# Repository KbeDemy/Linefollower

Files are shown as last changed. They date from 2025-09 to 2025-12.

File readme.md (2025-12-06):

# LineFollower

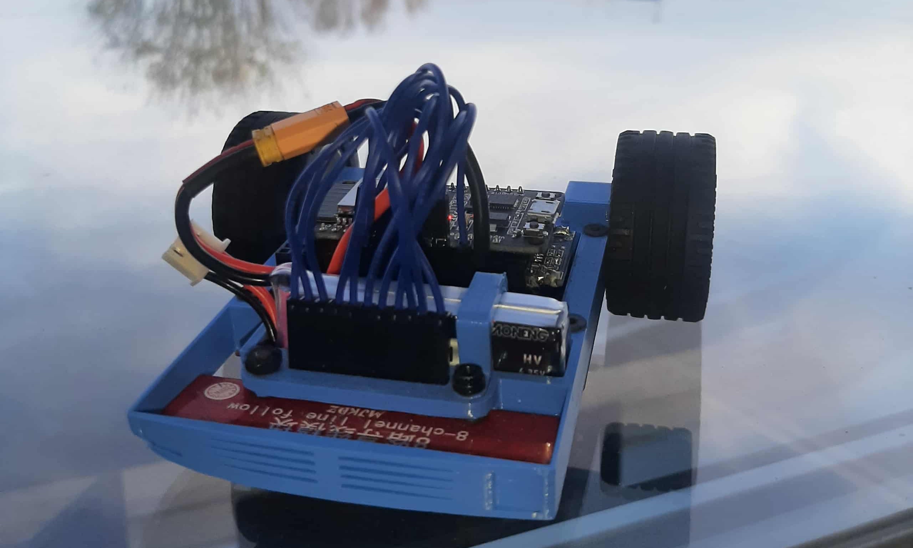
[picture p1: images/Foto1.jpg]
A description of my image


## specifications

microcontroller: ESP32-S3

motors: Aslong JGA12-N20-30 DC-Transmissiemotor 6V - 500RPM 

h-bridge: TB6612FNG 

sensors: 8x IR Lijn Tracking Module

batteries: LIHV 2s 300mAh

wireless communication: Bleutooth

distance sensor - motors: 90mm

weight: 150 Gr

speed: 0.27 m/s

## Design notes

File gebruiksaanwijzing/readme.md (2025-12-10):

Gebruikershandleiding: LineFollow Robot

Deze handleiding beschrijft de veilige werking, draadloze bediening en configuratie van de LineFollow robot via de bijbehorende applicatie.
Veiligheidsinstructies: Batterijgebruik
Opladen & Batterijtype

De robot gebruikt een LiPo HV 2S batterij met een volledige spanning van 8.7 V. Dit type batterij vereist uiterste voorzichtigheid.

    GEVAAR! LiPo-batterijen zijn zeer brandgevaarlijk bij onjuist gebruik of beschadiging.

    Gebruik enkel de juiste, door de fabrikant gespecificeerde LiPo-lader.

    Laad de batterij altijd op met de individuele cel-balansdraad aangesloten om overladen en celonbalans te voorkomen.

    Zorg dat de batterij fysiek is losgekoppeld van de robot tijdens het opladen.

    De robot en de USB poort van uw computer kan niet tegelijk de USB en de batterij aan doe dit nooit!
Robot Aan/Uit Schakelen

De robot is niet voorzien van een fysieke aan/uit-schakelaar.

    AAN: Sluit de batterij aan op de robot.

    UIT: Koppel de batterij fysiek los van de robot.

Draadloze Communicatie & GUI Bediening

De robot communiceert via Bluetooth met de GUI, waardoor er geen handmatige commando's nodig zijn.
Verbinding Maken / Verbreken
Actie	Procedure
Verbinden	
1. Zorg dat de robot is ingeschakeld (batterij aangesloten).
2. Open de app en ga naar de Connectie Tab.
3. Druk op de knop Verbinden. De app zal de status 'Verbonden' weergeven.
   
Verbreken	
De verbinding wordt verbroken door: 
1. In de app op Verbreken te drukken.
2. De applicatie te sluiten.
3. De batterij fysiek uit de robot te halen.

De Vier Applicatie Tabs
1. Connectie Tab 

Toont de huidige verbindingsstatus en bevat de knoppen Verbinden en Verbreken.
2. Sensoren Tab 

Deze tab geeft de live data van de lijnsensoren weer.

    Visualisatie: Een balkgrafiek toont de uitgelezen sensorwaarden.

    Besturingsknoppen:
        Kalibreer Wit/Zwart: Zie de sectie Kalibratie hieronder.

3. Settings Tab
   
Deze tab is bedoeld voor het configureren van de robotparameters.
      
      Start: Start de automatische lijnvolgroutine (PID-controle).
      Stop: Stopt de robot onmiddellijk en schakelt de PID-lus uit.
      Parameters: 
      de Basis Snelheid (0-255), 
      
      de PID-parameters (Kp, Ki, Kd) 
      
      het minimaal contrast tussen zwart en wit wanneer de robot uitvalt en
      
      de loogdaarlaatfilter op de position.
      
      Testmodus (ZQSD): Dit biedt de mogelijkheid om de motoren manueel te testen en besturen met de ZQSD-toetsen (of vergelijkbare controls).

      Belangrijk: Manuele besturing is alleen mogelijk wanneer u in deze tab bent. Dit is handig om de robot na lijnverlies snel en handmatig terug op de lijn te plaatsen.

5. Plot Tab 

Deze tab dient voor het analyseren van de prestaties na een run.

    Run Selectie: U kunt eerder uitgevoerde runs selecteren en de data ervan terugkijken.

    Plot Opties: U kunt kiezen welke data wordt weergegeven:

        Individuele sensorwaarden.

        Configuratie-instellingen van de run (Kp, Ki, Kd, Speed).

        De cruciale regelvariabelen: Output (de stuurcorrectie van de PID-regelaar) en Position (de berekende lijnpositie).

Analyse: U kunt inzoomen op de grafiek om oscillatie te detecteren en uw PID-instellingen te finetunen.
Shutterstock

    Verkennen

Kalibratie (Normalisatie)

Kalibratie is het proces waarbij de sensorwaarden softwarematig worden genormaliseerd. Dit zorgt ervoor dat de robot de maximale contrastinformatie tussen de witte ondergrond en de zwarte lijn benut, en maakt de sensoren onderling gelijk.
Stappenplan

    Installeer de App: Ga naar de Connectie Tab en verbind met de robot.

    Kalibratie WIT (Minimale Waarden):

        Plaatsing: Plaats de robot op de witte achtergrond van het parcours dat u gaat gebruiken.

        Controle: Ga naar de Sensoren Tab en controleer of alle sensorbalken een lage waarde (bijna allemaal 'wit') aangeven.

        Uitvoeren: Druk op de knop Kalibreer WIT.

    Kalibratie ZWART (Maximale Waarden):

        Plaatsing: Plaats de robot met de sensoren direct op de zwarte lijn van het parcours.

        Controle: Ga naar de Sensoren Tab en controleer of alle sensorbalken een hoge waarde (bijna allemaal 'zwart') aangeven.

        Uitvoeren: Druk op de knop Kalibreer ZWART.

Let op: Het is cruciaal dat u deze stappen uitvoert op de exacte materialen (wit/zwart) die u tijdens de run zult gebruiken.

Aanbevolen Parameters

De robot rijdt stabiel met de volgende parameters:

Kp	7	

Ki	0	

Kd	0	

Speed	140 	De basissnelheid van de robot.

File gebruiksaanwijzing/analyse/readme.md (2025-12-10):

#  Analyse van het Linefollower Project

Dit document vat de bevindingen en conclusies samen die zijn voortgekomen uit de analysefase van de linefollower-robot. Het project toonde aan dat de beperkingen van de mechanische constructie de prestaties van zelfs geavanceerde softwarematige oplossingen (zoals PID) overtroeven.

---

## 1.  De Logica van de PID-Regelaar

### Uitgebreide Testen vs. Mechanische Beperkingen
Tijdens de ontwikkelingsfase is er uitgebreid geëxperimenteerd met verschillende soorten en configuraties van de PID-regelaar. Hoewel de PID-logica essentieel is voor het sturen, werd al snel duidelijk dat verdere optimalisatie van de parameters of de implementatie **geen significante snelheidsverbetering** meer opleverde.

De primaire reden hiervoor is de **constructie van de robot**. De batterij, die een aanzienlijk gewicht vormt, is te ver van de motorassen geplaatst. Dit verhoogt het traagheidsmoment en de onbalans, waardoor de robot fysiek niet in staat is om sneller door bochten te gaan, onafhankelijk van hoe perfect de PID-correctie ook is. De gewichtsverdeling zou idealiter **dichter bij de motorassen** moeten liggen.

---

## 2.  Sensor Data en de Vreemde 'Glitch'

### Het Filter dat de Robot Vertraagde

Toen ik grafiek bekeek (de afbeelding):
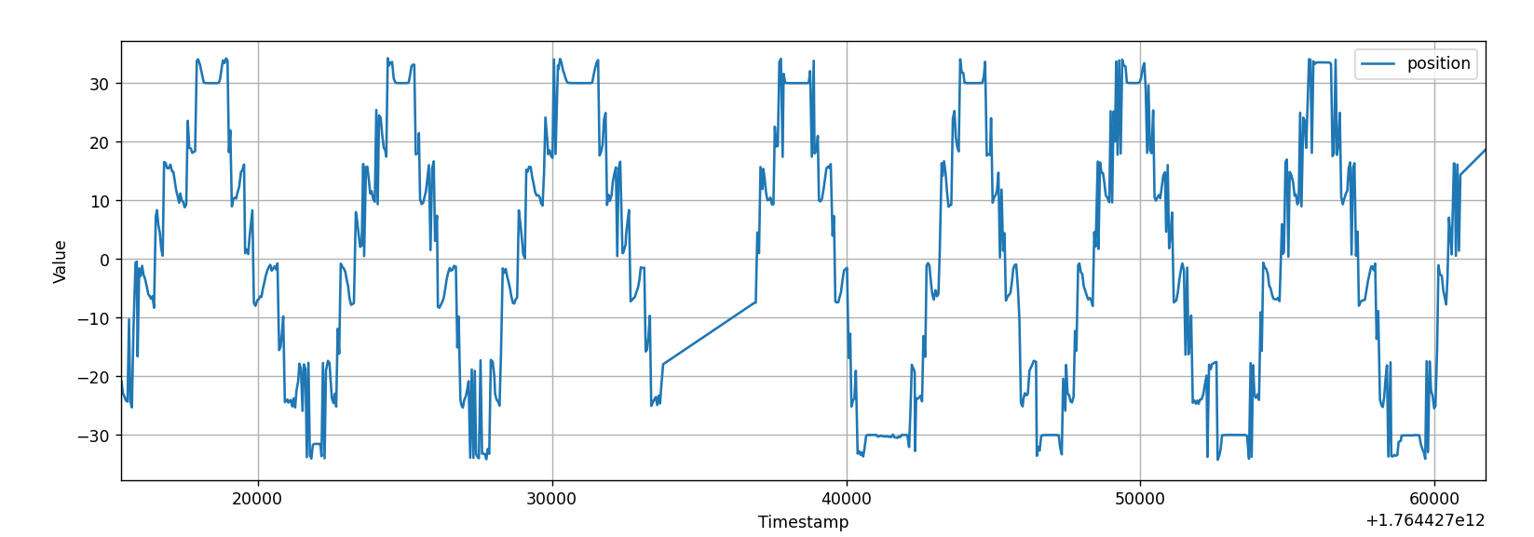
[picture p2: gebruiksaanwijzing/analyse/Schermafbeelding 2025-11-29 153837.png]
Grafiek Position Data

... zagen we dat de positiegegevens een beetje schommelden ('ruis'). ik dacht dat een filter (low pass, hoog frequente signalen eruit halen)

Het leek op de grafiek alsof het filter hielp:

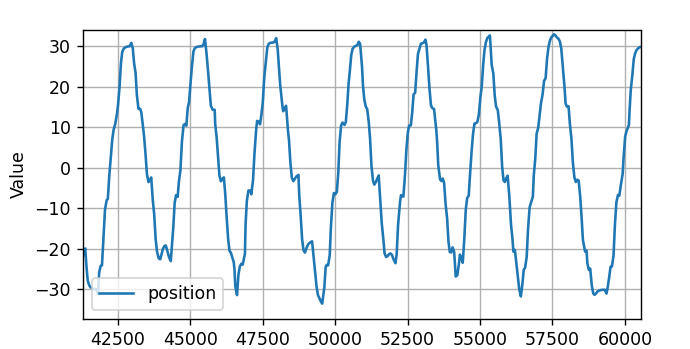
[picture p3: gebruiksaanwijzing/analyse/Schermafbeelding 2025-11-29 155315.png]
Grafiek Filterd Data


### Waarom het Filter Fout was
Tijdens het rijden bleek de filtering een slecht idee:

1.  **Vertraging:** Het filteren kost tijd. omdat de hoogfrequente signalen eruit werden gefilterd, betekent dit ook dat de scherpe bochten wat ook een hoogfrequent signaal is er uit wordt gefilter daardoor kreeg de robot de positie-informatie te laat door.
2.  **Gevolg:** De robot stuurde daardoor te laat en werd trager.
3.  **De Vreemde Glitch:** Wat we leerden, is dat de oorspronkelijke schommelingen in de data de robot tijdens het rijden helemaal niet stoorden. Het was een vreemde fout in de meting zelf ('a rare quirk'), en het was beter om de data snel binnen te krijgen dan om het schoon te maken.

## 3.  Conclusie over Analyse en Telemetrie 

### De Prijs van Debugging
Achteraf gezien was de inspanning die is gestoken in het bouwen van het analysesysteem en de visualisatie waarschijnlijk niet de moeite waard in verhouding tot de prestatiewinst.

Het systeem verstuurt alle analysedata in JSON-formaat, wat een aanzienlijke overhead met zich meebrengt voor de microcontroller. Hierdoor wordt de code zelf merkbaar vertraagd. De robot zou veel sneller kunnen opereren zonder deze telemetrie.

Gelukkig kan deze vertraging gedeeltelijk worden beperkt: de telemetrie kan worden uitgeschakeld in de sensortab, met de radiobutten, waardoor de prestaties van de robot tijdens een run kunnen worden verbeterd.

Ook was de telemtrie tool handig bij het debuggen van "gemakelijk fouten", je ziet de sensor waarden wat het wel gemakelijk maakt om de fouten op te sporen.

Er zijn zeker betere manieren om dit te doen

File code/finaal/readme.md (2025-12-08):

#  LineFollow_V2 - Firmware Architectuur en Logica

Dit project is de C++ firmware voor een lijnvolgrobot, PID-regulatie en draadloze communicatie via Bluetooth. De code is gestructureerd voor een **ESP32** microcontroller.

---

## Kernstructuren (`struct`)

De code maakt intensief gebruik van C++ `structs` om gerelateerde data te organiseren, wat de leesbaarheid en het beheer van de robotstatus verbetert:

* **`Sensor`**: Bevat de pin, kalibratiewaarden (`zwart`, `wit` uit EEPROM), ruwe meting (`waarde`) en de genormaliseerde meting (`norm`).
* **`Motor`**: Bevat het motornummer, de huidige snelheid (`speed`) en de fysieke PWM/IN1/IN2 pinnen.
* **`pidController`**: Bevat de operationele toestand van de PID-lus (`kp`, `ki`, `kd`, `error`, `integral`, `derivative`, `output`).
* **`ConfigParams`**: De structuur die **alle** door de gebruiker te configureren parameters bevat (PID-termen, `power`, `interval`, `filterAlpha`, `contrastDrempel`). Dit blok wordt als geheel opgeslagen in de EEPROM.
* **`status robot`**: Een globale struct die de lopende toestand van de robot bijhoudt (`run`, `verbonden`, `eenLijn`).

---

## De Hoofdregelcyclus (`loop()`)

De `loop()` functie voert twee hoofdtaken uit op basis van getimede intervallen:

### 1. Bluetooth Communicatie (Niet-blokkerend)

De code controleert continu (`SerialBT.available()`) op inkomende berichten:

* **Handshake:** Verwerking van de **`PING`**/**`PONG`** routine voor verbindingbeheer en timeout-controle.
* **JSON Parsing:** Inkomende JSON-berichten worden verwerkt om **runtime configuratie** of **commando's** te ontvangen (via functies als `handlePid`, `handleSpeed`, `calibWit`).
* **Controle:** Configuratie-wijzigingen worden enkel geaccepteerd wanneer `robot.run` **`false`** is, om de controlelus niet te verstoren tijdens het rijden.

### 2. De Regelcyclus (PID / Sensorverwerking)

De cruciale lus wordt uitgevoerd op basis van een variabele intervaltimer (`calc.interval`, standaard 2000 microseconden, dus 500 keer per seconde).

#### A. Sensor Normalisatie

* De functie `sensorNormalisatie()` leest de ruwe analoge waarden en gebruikt de gekalibreerde `wit` en `zwart` waarden om een **genormaliseerde** waarde (`0` tot `4095`) te berekenen.

#### B. Positiebepaling

* De code bepaalt de sensor met de hoogste genormaliseerde waarde (`index`).
  
* De locatie van de lijn wordt berekend met Kwadratische Interpolatie, die de pieksensor (s1) en zijn twee directe buren (s0, s2) analyseert om een vloeiende position te bepalen (geschaald van -30.0 tot 30.0). Om de interpolatie te laten werken wanneer de lijn de uiterste sensoren raakt (en er slechts één buur is), gebruikt de code virtuele sensoren.

    Logica: De ontbrekende buitenste buur krijgt een vaste waarde van 0.0f toegekend.

    Doel: Door de interpolatie de waarde van 0.0f te laten meenemen, behoudt de code de analoge nauwkeurigheid van de methode tot aan de rand. Dit voorkomt een abrupte (digitale) stuurcorrectie en               zorgt voor stabiele stuuracties wanneer de robot de randen van de lijn volgt.
    
* Deze ruwe positie wordt door een **Laagdoorlaatfilter** gehaald (`filterPosition`) met `filterAlpha` om ruis te dempen en de stabiliteit te verhogen. (aanpasbaar in GUI)

#### C. Lijnverliesdetectie (`geenLine`)

* De functie `geenLine()` berekent het **contrast** (`maxWaarde - minWaarde`) tussen alle genormaliseerde sensoren.
* Als dit contrast onder de `contrastDrempel` (een configureerbare waarde) valt, wordt aangenomen dat de lijn verloren is.
* Bij een overgang van 'lijn gevonden' naar 'lijn verloren' (`positieve edge`) wordt `robot.run` onmiddellijk op `false` gezet, en gaan de motoren stil.

#### D. PID-Uitvoering

* Als `robot.run` **`true`** is, roept de lus `updatePID(filterPosition, power)` aan.
* De PID-output wordt berekend op basis van de `error` (die gelijk is aan `-filterPosition`), de geaccumuleerde `integral` en de berekende `derivative`.
* De output wordt gebruikt om de basissnelheid (`power`) te moduleren en de snelheden voor de linker- en rechtermotor te bepalen, wat resulteert in sturing.

#### E. Motor Aansturing

* De functie `motors.set_speed(motoren[0].speed, motoren[1].speed)` stuurt de uiteindelijke snelheden van de twee motoren aan 

## Configuratie Permanentie

De firmware zorgt voor permanente opslag van configuraties via de `EEPROM` bibliotheek:

* **EEPROM Adressen:** Adressen worden dynamisch beheerd via de `eepromOffsets` structuur om flexibiliteit in structuurgrootte te behouden.
* **First Flash Check:** Bij de eerste opstart na een flash wordt gecontroleerd op een unieke waarde (`EEPROM_FIRST_CHECK`). Zo niet, dan worden alle sensor- en `ConfigParams` standaardwaarden weggeschreven.
* **Debounced Commit:** De functie `markConfigAsDirty()` wordt aangeroepen na elke configuratiewijziging. De daadwerkelijke `EEPROM.commit()` vindt echter pas plaats in de `loop()` nadat er 2 seconden **geen** configuratiewijzigingen zijn geweest. Dit vermindert de slijtage van het EEPROM-geheugen.

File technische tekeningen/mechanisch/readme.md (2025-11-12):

## Lijst van mechanishe tekeningen
<br />

| |naam|omschrijving|
|-|----|---|
|1|DNaarLegoCross|Koppeling motor wiel| 
|2|Frame|Frame van Robot|
|3|Batterij-Houder|houd batterij op zijn plaats|

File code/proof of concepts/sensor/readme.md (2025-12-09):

# Sensoren Proof of Concept: Onafhankelijke ADC-Uitlezing (ESP32)

Dit project toont de basisfunctionaliteit van een ESP32 om **8 analoge sensoren** onafhankelijk uit te lezen, waarbij het volledige 12-bit bereik van de Analoog-naar-Digitaal Converter (ADC) wordt benut.

---

## 1.  Doelstelling

* Aantonen dat minimaal 6 (in dit geval 8) analoge ingangen onafhankelijk kunnen worden uitgelezen.
* Benutten van het volledige ADC-bereik (0-4095).
* Basisimplementatie zonder complexe verwerking (calibratie/normalisatie).

## 2.  Hardware Vereisten

| Component | Beschrijving |
| :--- | :--- |
| **Microcontroller** | ESP32-compatibel bord |
| **Analoge Sensoren** | Minimaal 8 sensoren die variabele spanning leveren (0V - 3.3V). |

## 3.  Pinconfiguratie

De code leest de waarden van **8 verschillende GPIO-pinnen** die zijn geconfigureerd als Analoge Ingangen (ADC).

| Sensor ID | ESP32 GPIO Pin | ADC-bereik |
| :---: | :---: | :---: |
| **S1** | 33 | 0-4095 |
| **S2** | 32 | 0-4095 |
| **S3** | 27 | 0-4095 |
| **S4** | 14 | 0-4095 |
| **S5** | 39 | 0-4095 |
| **S6** | 36 | 0-4095 |
| **S7** | 34 | 0-4095 |
| **S8** | 35 | 0-4095 |

---

## 4.  Code

### Functie: Getimede Uitlezing

De `loop()`-functie zorgt ervoor dat de 8 analoge waarden slechts **één keer per seconde** worden uitgelezen en afgedrukt.

```cpp
void loop() {
  if (millis() - vorigeMillis >= 1000){
    // Lees 8 pinnen uit en formatteer de data...
    // ...
  }
}
```
Uitlezing en Formattering

De kern van de uitlezing is: $$ \text{Outputwaarde} = \text{analogRead}(\text{GPIO}) $$ Deze output is een integer tussen 0 en 4095 (12-bit resolutie).

De sprintf()-functie verzamelt de 8 onafhankelijke meetwaarden in één overzichtelijke string voor de Seriële Monitor:

S1: [Waarde] , S2: [Waarde] , S3: [Waarde] , ...

## 5. Ingebruikname

    Sluit de 8 sensoren aan op de overeenkomstige GPIO-pinnen (32, 33, 27, 14, 39, 36, 34, 35).

    Upload de code naar de ESP32.

    Open de Seriële Monitor (115200 baud) om de onafhankelijke uitlezingen te observeren.

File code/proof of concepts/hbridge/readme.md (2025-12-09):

#  H-Brug Proof-of-Concept met de TB6612FNG Dual DC Motor Driver

Deze proof of concept demonstreert het principe van de **H-Brug** voor de onafhankelijke en traploze regeling van twee DC-motoren (snelheid en draairichting) met behulp van de TB6612FNG dual motor driver en een ESP32-microcontroller.

---

## 1.  Hardware Vereisten

| Component | Beschrijving | Opmerkingen |
| :--- | :--- | :--- |
| **Microcontroller** | ESP32-compatibel bord | Nodig voor geavanceerde PWM (LEDC) en snelle GPIO-schakeling. |
| **Motor Driver** | TB6612FNG Dual DC Motor Driver | Bevat de twee noodzakelijke H-bruggen. |
| **DC Motoren** | 2 x DC Motoren | De belasting die wordt aangestuurd. |
| **Voeding** | Externe voeding (5-12V) | **Belangrijk:** Voor de motoren (VM/VCC), gescheiden van de logica. |

> 

## 2.  Software Vereisten

* Arduino IDE (of PlatformIO).
* De meegeleverde `TB6612.h` en `TB6612.cpp` bibliotheekbestanden, verpakt als de `MotorDriver` klasse.

---

## 3.  Pinconfiguratie (ESP32)

De TB6612FNG wordt als volgt aangesloten op de ESP32:

| TB6612 Pin | ESP32 Pin | Functie | Mechanisme |
| :--- | :--- | :--- | :--- |
| **AIN1** | 17 | Richting Motor A | H-Brug Input 1 (IN) |
| **AIN2** | 16 | Richting Motor A | H-Brug Input 2 (IN) |
| **PWMA** | 25 | Snelheid Motor A | PWM (Enable) |
| **BIN1** | 18 | Richting Motor B | H-Brug Input 1 (IN) |
| **BIN2** | 19 | Richting Motor B | H-Brug Input 2 (IN) |
| **PWMB** | 26 | Snelheid Motor B | PWM (Enable) |

> **Opmerking:** Zorg ervoor dat de **STBY**-pin van de TB6612 permanent op **HIGH** is aangesloten om de driver in te schakelen.

---

## 4.  Stappenplan (Ingebruikname)

1.  **Aansluiten Hardware:** Verbind alle componenten volgens de pinconfiguratie. Sluit de DC-motoren aan op de **AOUT1/AOUT2** en **BOUT1/BOUT2** uitgangen en zorg voor de juiste stroomaansluitingen (VM/VCC/GND).
2.  **Code voorbereiden:** Plaats de meegeleverde bronbestanden in een map `TB6612` in de bibliotheekmap van je schets.
3.  **Uploaden:** Upload de hoofdcode (met de `loop()`) naar de ESP32.
4.  **Testen:** Open de Seriële Monitor (`115200` baud). De motoren starten de testcyclus.

---

## 5. Code Analyse (Werking & H-Brug Logica)

### 5.1. De `loop()` functie: Onafhankelijke & Traploze Regeling

De `loop()` demonstreert het Proof-of-Concept door beide motoren tegelijkertijd, maar onafhankelijk, door een volledige snelheidscyclus te sturen.

```cpp
void loop() {
  for(int i = -255; i < 255; i++){
    motors.set_speed(i,-i);
  }
}
```

Motor A (Snelheid i): Variëert van −255 (Max. Achteruit) →0 (Stilstand) →+255 (Max. Vooruit).

    Motor B (Snelheid -i): Variëert tegenovergesteld, van +255 (Max. Vooruit) →0 (Stilstand) →−255 (Max. Achteruit).

### 5.2. De set_speed(int16_t motor_a, int16_t motor_b) Functie

Deze functie vertaalt de invoersnelheid (bereik: [−255,255]) naar de fysieke sturing van de motor.
### 5.3 Richtingbepaling (H-Brug Logica)

De draairichting van de motor wordt bepaald door de logische toestand van de twee IN-pinnen van de H-brug (AIN1/AIN2 of BIN1/BIN2). Dit verandert de polariteit over de motor.

| Invoer Snelheid ($\text{motor}$) | IN1 ($\text{AIN1}$ of $\text{BIN1}$) | IN2 ($\text{AIN2}$ of $\text{BIN2}$) | Resultaat (Draairichting) |
| :---: | :---: | :---: | :--- |
| **Positief** $(>0)$ | $\text{Hoog} \text{ (Set)}$ | $\text{Laag} \text{ (Clear)}$ | **Voorwaarts** |
| **Negatief** $(<0)$ | $\text{Laag} \text{ (Clear)}$ | $\text{Hoog} \text{ (Set)}$ | **Achterwaarts** |
| **Nul** $(0)$ | $\text{Laag} \text{ (Clear)}$ | $\text{Laag} \text{ (Clear)}$ | **Stilstand** (Rem of Freewheel) |

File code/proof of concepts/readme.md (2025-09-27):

# Proof of Concepts

Een proof of concept is een combinatie van minimale hard- en software om eenvoudig aan te tonen dat iets werkt.  
Proof of concepts kunnen enerzijds als eerste poging dienen om een bepaald onderdeel van het project werkend te krijgen. Anderzijds kunnen ze tijdens het debuggen van het finale project dienen als test om eventuele hardware problemen te elimineren bij onduidelijke problemen.
<br />  
<br />
Een proof of concept bestaat uit
* een elektronisch schema (indien van toepassing)
* minimale code om de voorop gestelde zaken te demonstreren
* minimale uitleg / aandachtspunten
<br />
De elektronische schakelingen van de proof of concepts komen bij voorkeur overeen met deze van de uiteindelijke linefollower, zodat de code zonder aanpassingen op het finale project kan draaien.

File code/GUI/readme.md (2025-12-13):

# Linefollower - GUI Applicatie

Dit project is een Python-applicatie met een GUI gebouwd met PyQt6 en is gericht op het besturen/parametreren van de linefollower en dataanalyse van gereden runs

zie /schermafbeelding_ voor hoe de verschillende tabs er uit zien 

## Installatie

Volg deze stappen om het project lokaal op uw computer in te stellen en uit te voeren.

### 1. Project Klonen

Open uw commandoregel en download de code van GitHub:

```bash
git clone https://github.com/KbeDemy/Linefollower
cd code/GUI
```
### 2. Virtuele Omgeving Instellen (niet verplicht maar aanbevolen)

#### Maak een virtuele omgeving om ervoor te zorgen dat u systeem niet vervuilt en om conflicten te vermijden 
Creëer de omgeving:
  ```bash
  python -m venv venv
  ```
Activeer de omgeving:
  ```bash
  .\venv\Scripts\Activate
  ```
### 3. Dependencies Installeren

#### Installeer alle benodigde pakketten die in het requirements.txt bestand zijn gespecificeerd:

 ```bash
pip install -r req.txt
 ```
  Dit installeert alle vereisten, inclusief de GUI-bibliotheek (PyQt6), plotting tools (matplotlib), en seriële communicatie (pyserial).
#### De Applicatie Uitvoeren

Zodra de virtuele omgeving actief is en de installatie is voltooid, start u de applicatie met dit commando:

 ```bash
python main.py
 ```
De grafische gebruikersinterface zou nu moeten verschijnen.

### NOTE : Belangrijke Map- en Bestandsstructuur
  De applicatie is ontworpen om bepaalde bestanden en mappen automatisch aan te maken in de map waar u python main.py uitvoert.
#### 1. CSV-bestanden
      Wanneer: Als u in de GUI op de knop "Maak CSV" drukt.
     
      Locatie: Er wordt een nieuwe submap gemaakt genaamd csv_files (als deze nog niet bestaat).
     
      Doel: Alle geëxporteerde gegevens worden in deze map opgeslagen.

#### 3. Lokale Database
      Actie: De database wordt automatisch gecreëerd bij de eerste keer opstarten of wanneer een database-actie vereist is.
      
      Locatie: Het databasebestand (robot_data.db) wordt direct in de hoofdmap van de applicatie aangemaakt (naast main.py).
#### 4. Afbeeldingen van tabs
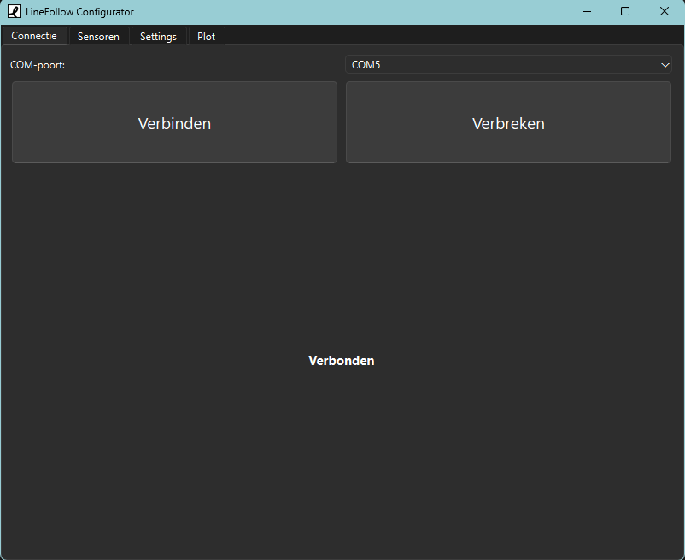
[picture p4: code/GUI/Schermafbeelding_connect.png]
abeelding_connect


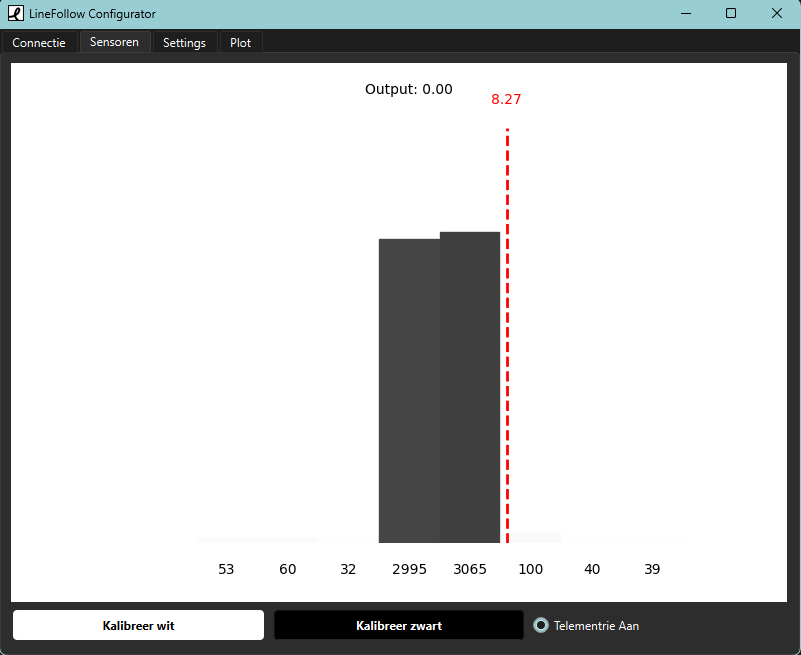
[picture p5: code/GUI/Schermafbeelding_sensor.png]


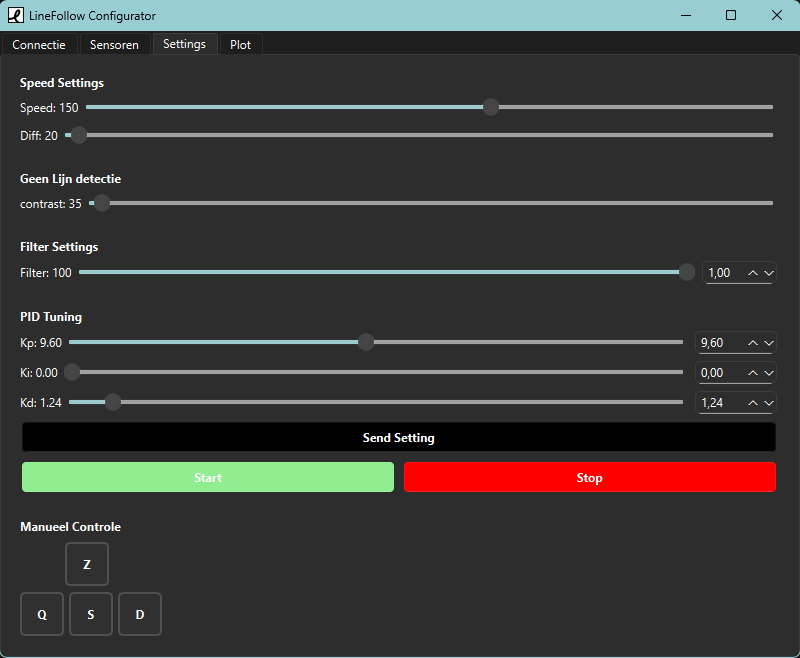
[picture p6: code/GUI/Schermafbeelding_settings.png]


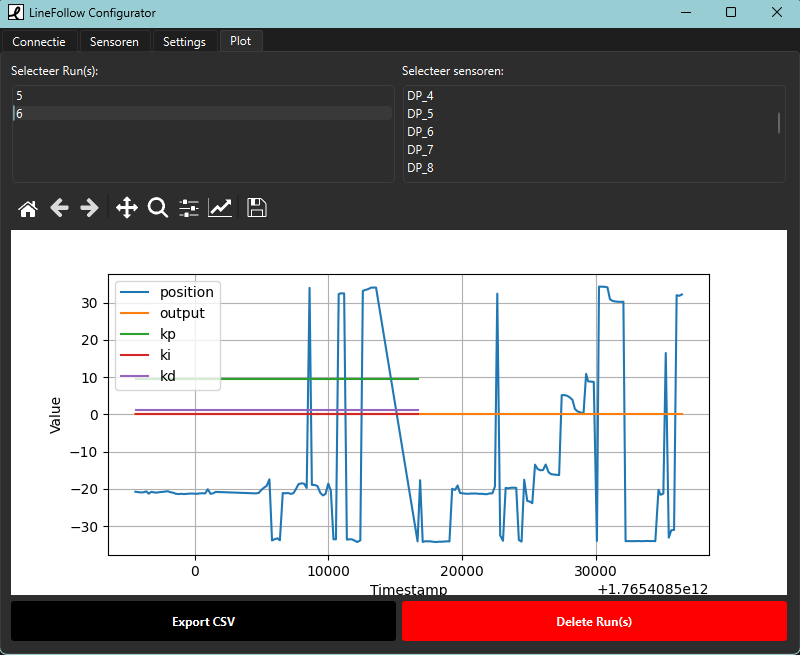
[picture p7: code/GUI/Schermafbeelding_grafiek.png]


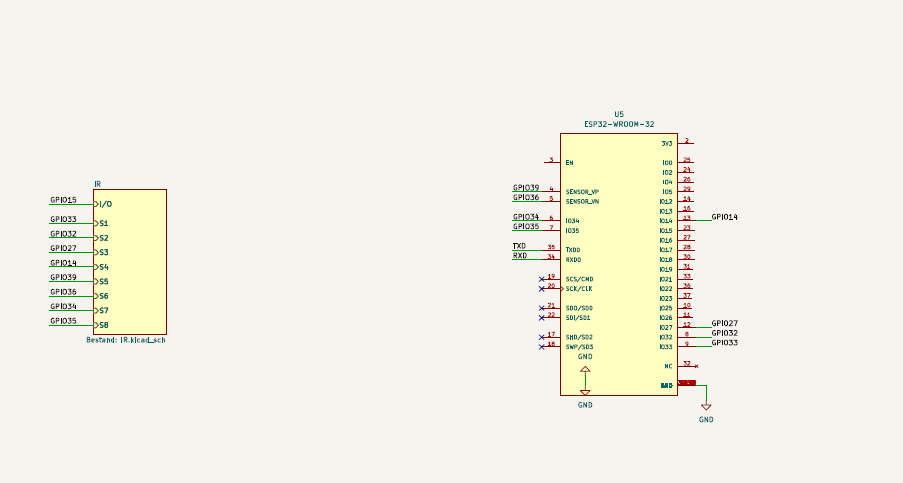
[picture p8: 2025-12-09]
code/proof of concepts/sensor/Sensoren.png

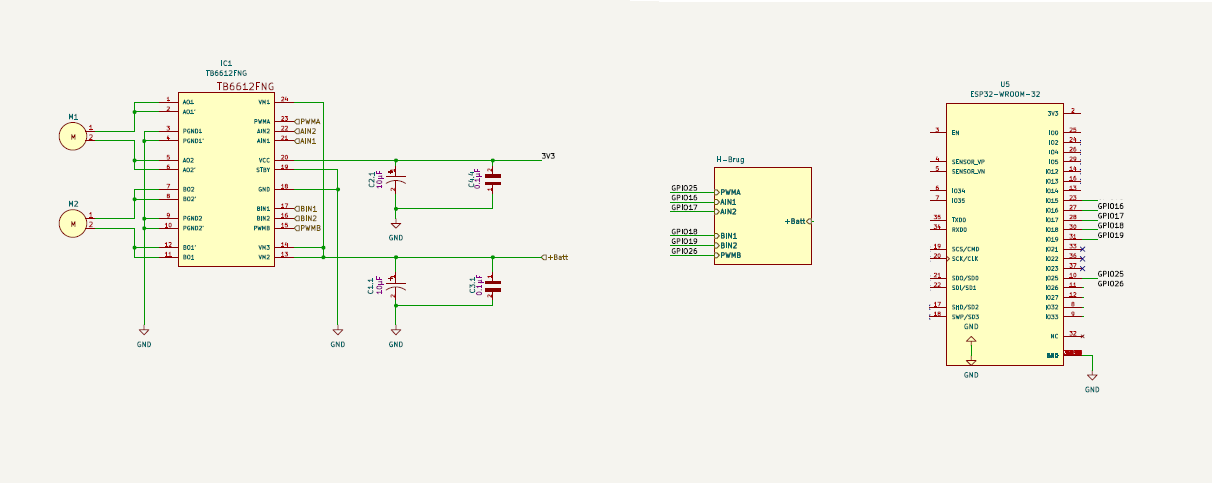
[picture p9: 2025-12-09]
code/proof of concepts/hbridge/H-brug.png

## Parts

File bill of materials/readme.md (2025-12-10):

#  BOM

| naam | omschrijving | nieuwe/recap | kostprijs/stuk | eenheid | aantal | subtotaal |
| :--- | :--- | :--- | :--- | :--- | :--- | :--- |
| elektrische draad | 0.05mm² | 1 | 0.00652 | €/cm | 15 | €0.10 |
| DnaarLegoCross | 3D print.zie /mechanisch ! 2 KEER ! | 1 | 0.01536 | €/g | 0.6 | €0.01 |
| 43.2 mm tire | LEGO | 0 | 0.39 | €/stuk | 2 | €0.78 |
| 43.2 mm wheel | LEGO | 0 | 0.39 | €/stuk | 2 | €0.78 |
| Aslong JGA12-N20-10 | 6V 1500RPM | 1 | 4.5 | €/stuk | 2 | €9.00 |
| GAONGNENG GNB LiHV 2s | 7.6V 300mAh 80C XT30 | 1 | 5.36 | €/stuk | 1 | €5.36 |
| ESP32-C3 DEV board | | 1 | 9 | €/stuk | 1 | €9.00 |
| DC-DC Step-down Buck Converter | 3A - 3.3V output | 1 | 3 | €/stuk | 1 | €3.00 |
| Countersunk Hex Socket Screw | M3 x 14 DIN 7991 | 0 | 0.2 | €/stuk | 4 | €0.80 |
| Hex Nut | M3 DIN 934 | 0 | 0.4 | €/stuk | 6 | €2.40 |
| TB6612FNG | Easy Motor Driver | 1 | 7 | €/stuk | 1 | €7.00 |
| 8x IR Lijn Tracking Module | 40mm Bereik | 1 | 3.5 | €/stuk | 1 | €3.50 |
| spacers | 7 mm | 0 | 0.01 | €/stuk | 2 | €0.02 |
| Button Head Socket Screw | M3 x 14 DIN 7380 | 0 | 0.3 | €/stuk | 2 | €0.60 |
| Body | 3D print.zie /mechanisch | 1 | 0.01536 | €/g | 19.04 | €0.29 |
| Batterijhouder | 3D print.zie /mechanisch | 1 | 0.01536 | €/g | 0.68 | €0.01 |
| Experimenteer printplaat | 5 x 7 cm | 0 | 0.65 | €/stuk | 1 | €0.65 |
| Vrouwelijke Header | (Pin Len: 5.5mm) | 1 | 0.9 | €/stuk | 2 | €1.80 |
| Vrouwelijke Header | (Pin Len: 2 mm) | 1 | 0.1 | €/stuk | 2 | €0.20 |
| xt30- male connector | >10 cm | 1 | 1.75 | €/stuk | 1 | €1.75 |
| dupont draadjes | 10 cm Blauw | 1 | 0.0372 | €/stuk | 11 | €0.41 |

## Totaaloverzicht

| Post | Waarde |
| :--- | :--- |
| **Totale Som** | **€47.46** (Afgerond) |

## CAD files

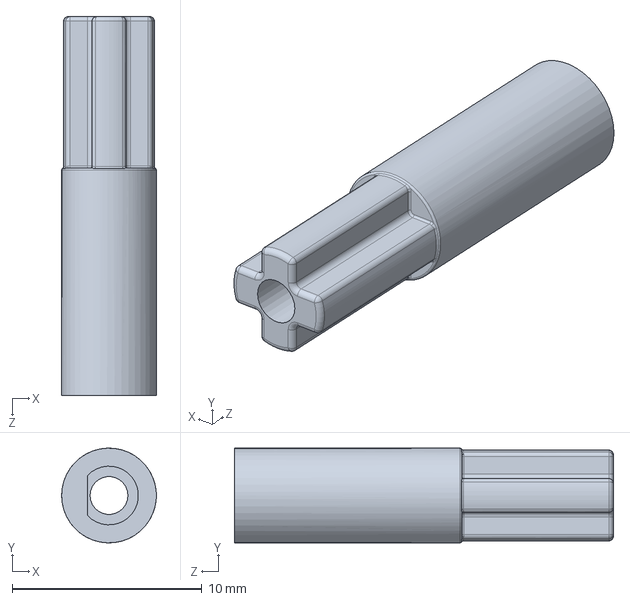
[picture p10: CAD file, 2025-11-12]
technische tekeningen/mechanisch/DnaarLegoCross.SLDPRT
5.00 x 5.00 x 20.0 mm

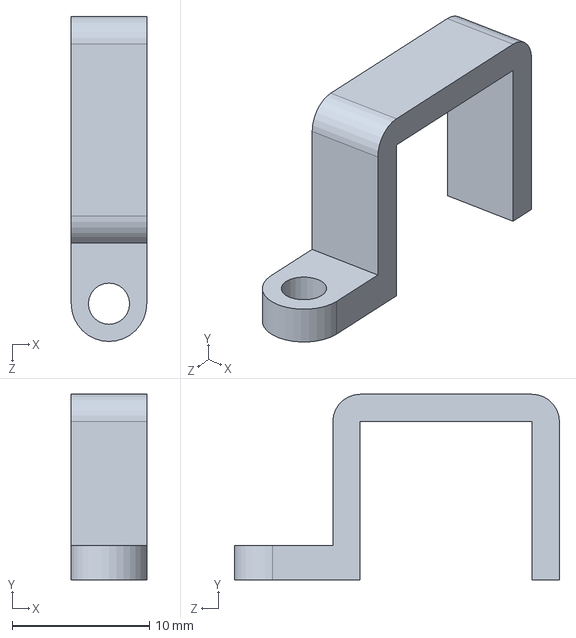
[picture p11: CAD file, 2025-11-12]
technische tekeningen/mechanisch/Batterij_Holders_V2.0.SLDPRT
5.50 x 13.5 x 23.6 mm

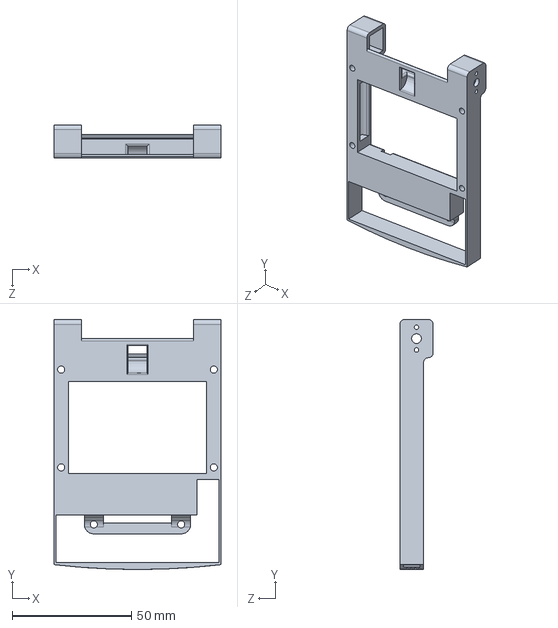
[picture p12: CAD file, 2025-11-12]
technische tekeningen/mechanisch/Frame.SLDPRT
70.0 x 104.8 x 14.0 mm

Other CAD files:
technische tekeningen/mechanisch/Batterij_Holders_V2.0.STL
technische tekeningen/mechanisch/DnaarLegoCross.STL
technische tekeningen/mechanisch/Frame.STL

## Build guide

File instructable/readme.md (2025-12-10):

#  Instructable: Bouw van de Line Follower Robot

Dit document is een stappenplan dat beschrijft hoe de Line Follower Robot gebouwd moet worden, uitgaande van de *Bill of Materials* en de *Technische Tekeningen* (met name *PlanB*). De bijgevoegde afbeeldingen dienen als visuele referentie tijdens de montage.

(niet alle stappen hebben een afbeelding, wanneer het niet duidelijk is kan je altijd eens kijken of er geen duidelijkere afbeelding in /instructable staan)

---

##  Deel 1: Voorbereiding en Componenten 

### Stap 1: Componenten Bestellen en 3D-printen
* Bestel alle elektronische componenten uit de *Bill of Materials*.
* 3D-print de mechanische componenten die beschreven staan in de map `/technishe tekeningen/mechanish`.
  
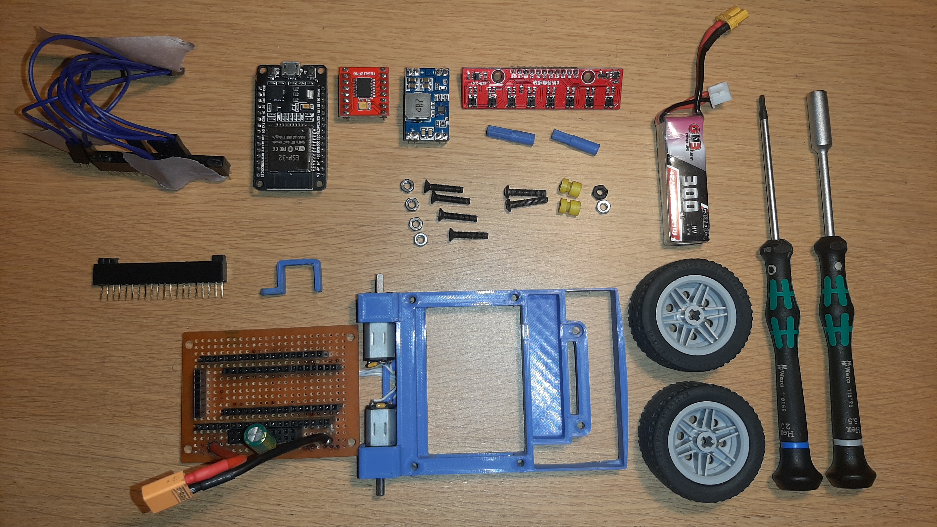
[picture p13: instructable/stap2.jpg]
componenten
  
### Stap 2: Pinnen op Breakout Boards Solderen
* Soldeer de *header pins* aan alle componenten (ESP-32, Motor Driver, Buck Converter, en de 8-channel Line Follow sensor).
    > **Opmerking:** Er is gekozen voor breakoutboards om het solderen te vereenvoudigen en componenten gemakkelijk te kunnen vervangen.

### Stap 3: Voorbereiden van de Perforatieprint (Prototyping Board)
Dit is de basis van de bedrading.

1.  Soldeer de **vrouwelijke header pinnen** aan het perforatieprintje. Zorg voor voldoende ruimte tussen de pinnen en het 3D-geprinte frame (zie afbeeldingen).
2.  **Voeding:** Soldeer de **male extender cord** (voor de batterijvoeding) aan de printplaat. Boor gaten in de printplaat zodat de uiteinden de + en - pads kunnen raken.
3.  **Condensator:** Soldeer een **condensator van 1000 µF** in parallel over de batterijspanning. Deze zal spanningspieken opvangen.
4.  **Motoren:** Soldeer 2 kleine condensatoren over de motoren zelf (dit is optioneel, maar aanbevolen om spanningspieken te vermijden).
5.  Soldeer draden aan de motoren om ze via het voorziene 'poortje' naar het printplaatje te leiden en aan te sluiten. 
6.  **Interne Bedrading:** Maak de juiste verbindingen (korte draadbruggen) tussen de toekomstige componenten (**ESP-32**, **Motor Driver**, **Buck Converter**) op de onderkant van het perforatieprintje. Volg hiervoor nauwkeurig het schema in *technishe tekeningen / schemaPlanB*.

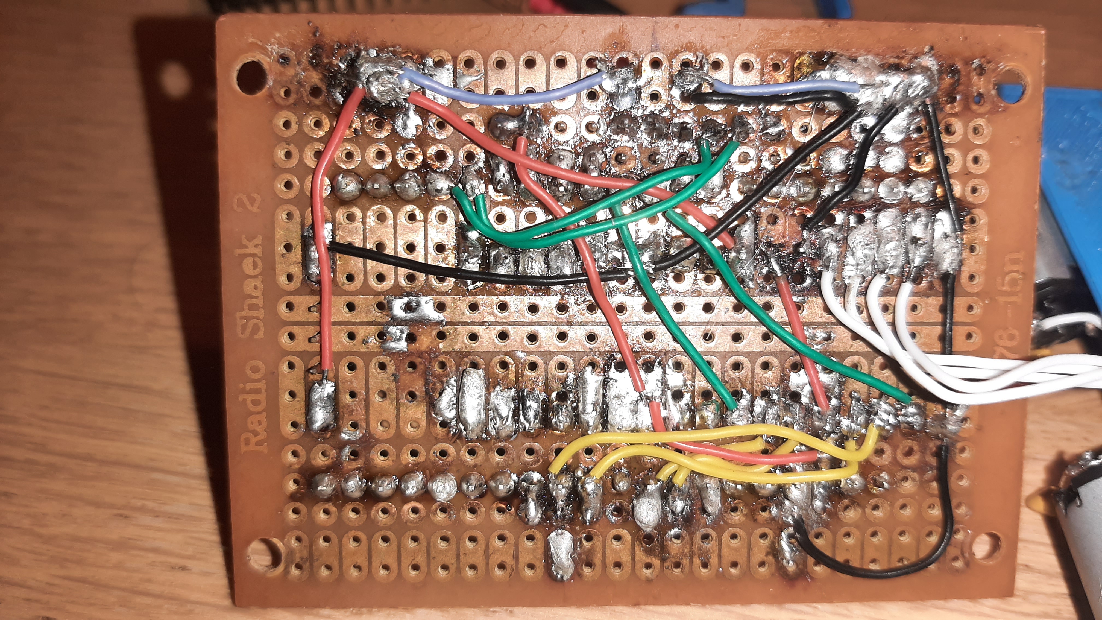
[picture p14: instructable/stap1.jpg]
printplaat
   

---

##  Deel 2: Montage en Installatie

### Stap 4: Montage van het Frame en de Printplaat
* Plaats het **perforatieprintje (met de motoren)** onder het 3D-geprinte frame.
* Lijn de gaten uit.
* Schroef het geheel aan elkaar met de 4 conische bouten en moeren.
    
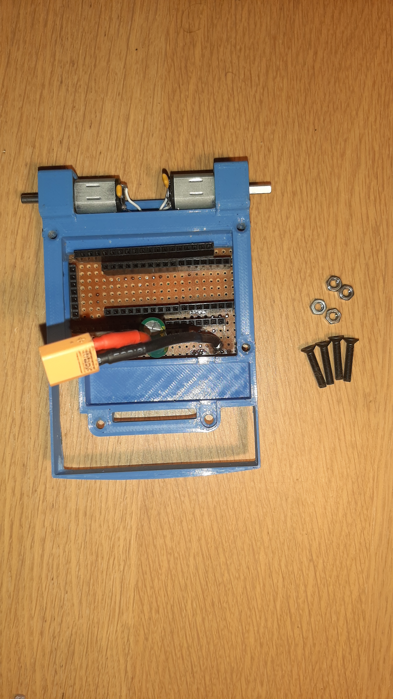
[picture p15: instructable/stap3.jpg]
stap4
  
  
### Stap 5: Montage van de Line Follower Sensor
* Plaats de **8-channel Line Follow sensor** in de voorziene opening aan de voorkant van het frame.
* plaats de batterijhouder juist 
* Schroef deze vast met de bijbehorende bouten en moeren.

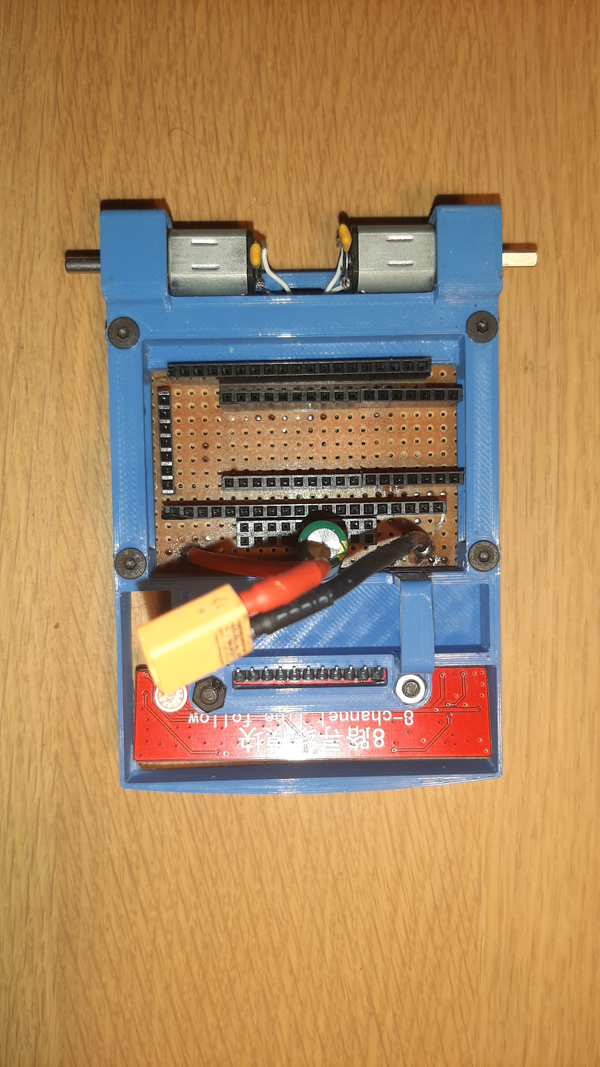
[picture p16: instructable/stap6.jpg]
stap4
   
### Stap 6: Plaatsen van de Hoofdcomponenten
* Plaats de **extender female pinnen** op de reeds gesoldeerde female pinnen van het perforatieprintje.
* Plaats de **ESP-32** op de extender pinnen. Zorg dat de ESP correct is georiënteerd.
* Plaats de **Motor Driver** (rood) en de **Buck Converter** (blauw) op de daarvoor bestemde plekken op de printplaat.
    
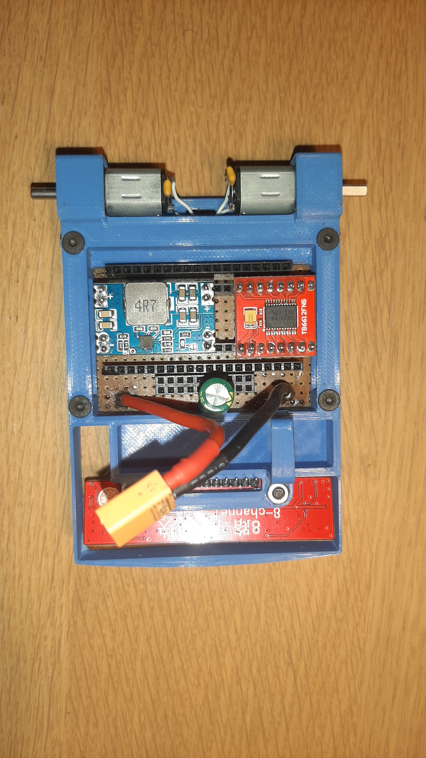
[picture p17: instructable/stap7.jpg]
stap4
   

---

##  Deel 3: Finale Aansluitingen en Afwerking 

### Stap 7: Aansluiten van de Sensoren
1.  **Sensor Aansluiting:** Neem **Dupont draadjes** en steek die in de overgebleven open female headers (die verbonden zijn met de ESP-pinnen).
2.  Maak de verbinding tussen deze headers en de pinnen van de **8-channel Line Follow sensor** volgens het schema.
   
### Stap 8: verlengde headers monteren en ESP32 monteren 
* plaats de verlengde headers op de andere headers
* monteer daarop de ESP32

### Stap 9: Finaliseren en Klaar voor Software
* Bevestig de wielen op de motorassen.
* Sluit de batterij aan op de XT30-connector.
* De robot is nu mechanisch en elektrisch geassembleerd.

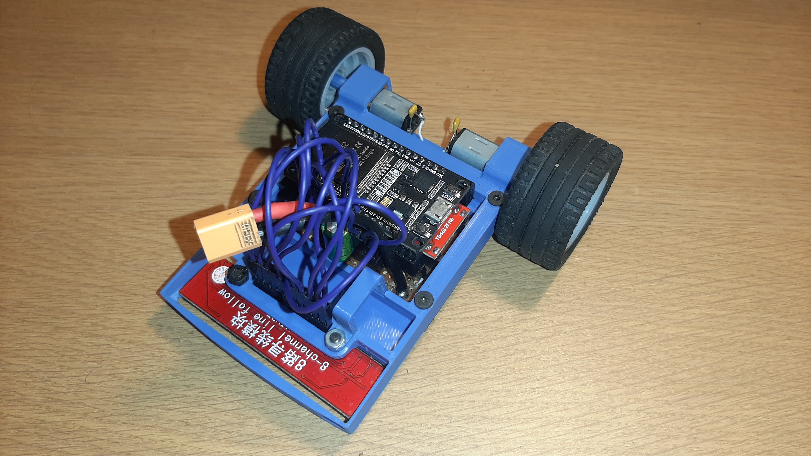
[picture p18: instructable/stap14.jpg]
stap4
   

---

## Deel 4: Microcontroller Programmeren en Software 

Dit deel beschrijft de stappen om de software op de ESP-32 microcontroller te krijgen en hoe u de robot veilig in gebruik neemt.

### Stap 10: Voorbereiding en Installatie van de Code

1.  **Software-omgeving:** Zorg ervoor dat de **Arduino IDE** (of een vergelijkbare omgeving zoals PlatformIO) correct is geïnstalleerd op uw computer en dat de **Board Support Package voor de ESP-32** is toegevoegd.
2.  **Code Downloaden:** Navigeer naar de map `/code/finaal/` in de projectbestanden.
3.  **Bestanden Bundelen:** Download alle bestanden uit deze map (dit zijn het hoofdprogramma (`.ino`), de implementatiebestanden (`.cpp`), en de headerbestanden (`.h`)).
4.  **Projectmap:** Plaats **alle gedownloade bestanden** in een **enkele nieuwe map** op uw computer. De naam van deze map moet exact overeenkomen met de naam van het `.ino` bestand.
5.  **Openen:** Open de map in de Arduino IDE. De IDE zal nu het volledige project met alle codebibliotheken en klassen herkennen.

### Stap 11: Compilatie en Uploaden naar de ESP-32

1.  **Board Selecteren:** Selecteer in de Arduino IDE de juiste ESP-32 ontwikkelingskaart (meestal **ESP32 Dev Module** of vergelijkbaar, afhankelijk van uw specifieke chip) onder het menu *Tools -> Board*.
2.  **Poort Selecteren:** Selecteer de seriële poort waaraan de ESP-32 is verbonden.
3.  klikt u op de knop **Uploaden** om de code over te brengen naar de ESP-32.

### Stap 12: Belangrijke Veiligheidswaarschuwingen

Lees deze waarschuwingen zorgvuldig door om schade aan de elektronica te voorkomen:

* **Batterij en USB Nooit Samen:** **Steek NOOIT de batterij en de USB-kabel tegelijkertijd in.** Dit kan leiden tot een stroomconflict, overmatige hitte, en permanente schade aan de ESP-32 en/of de batterij.
* **Motoren Testen via USB:** **Test of voed de motoren NOOIT via de USB-kabel van de ESP-32.** De ESP-32 heeft een interne 3.3V-regulator die niet ontworpen is om de hoge piekstroom te leveren die motoren vereisen. Dit kan leiden tot overbelasting, instabiliteit van de microcontroller, of falen van de regulator. Voed de motoren altijd via de externe batterij en de Motor Driver (gebruik de USB alleen voor programmeren).

### Stap 13: Installatie van de Gebruikersinterface (GUI/APP)

1.  Volg het stappenplan in de map `code/GUI/readme.md` om de bijbehorende gebruikersinterface (GUI/APP) te installeren op computer.

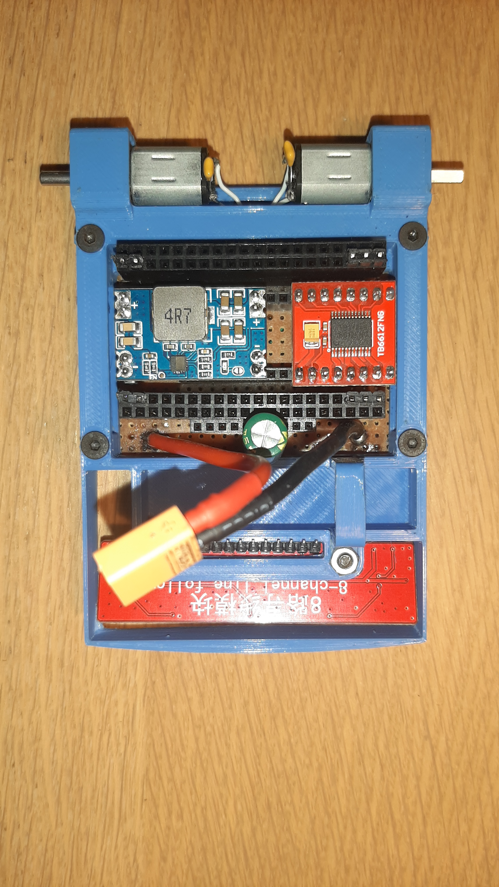
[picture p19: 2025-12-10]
instructable/stap8.jpg

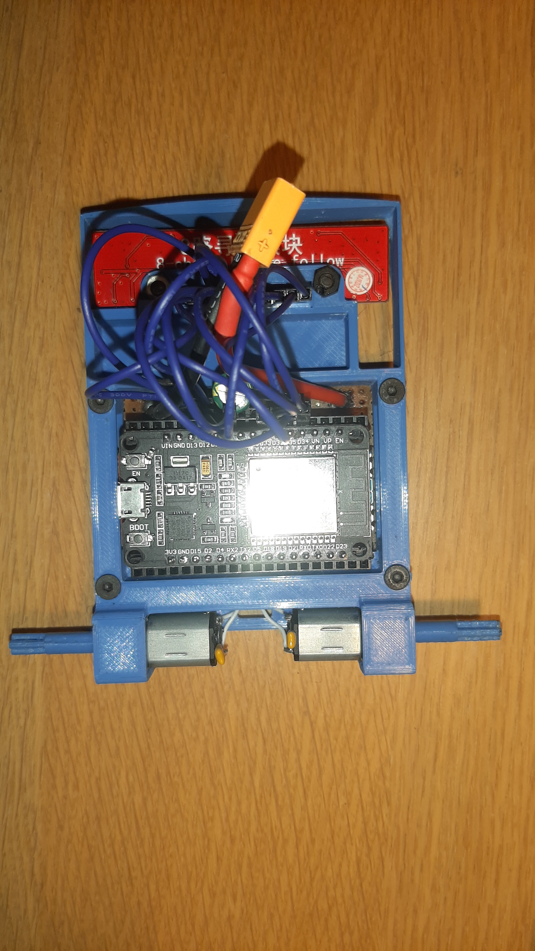
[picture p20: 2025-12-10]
instructable/stap13.jpg

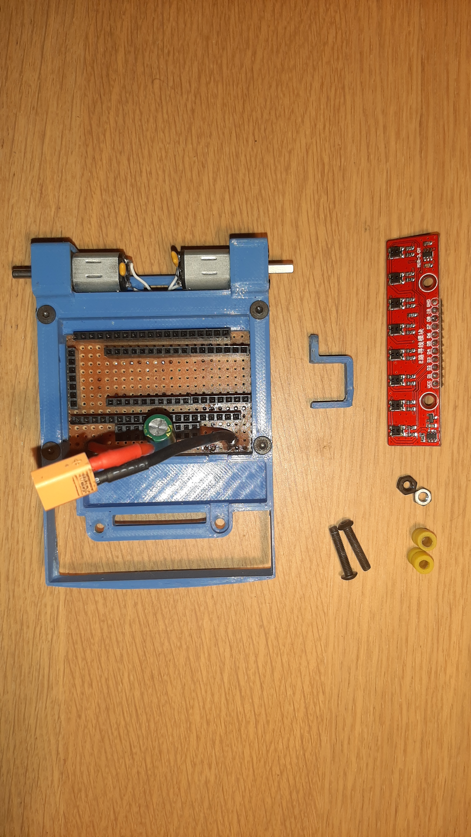
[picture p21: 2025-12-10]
instructable/stap.jpg

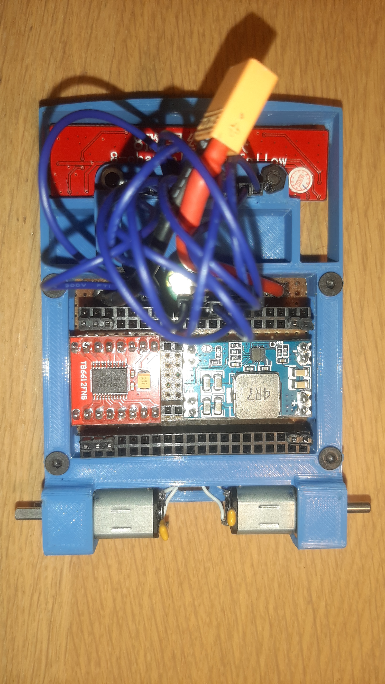
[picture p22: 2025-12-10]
instructable/stap11.jpg

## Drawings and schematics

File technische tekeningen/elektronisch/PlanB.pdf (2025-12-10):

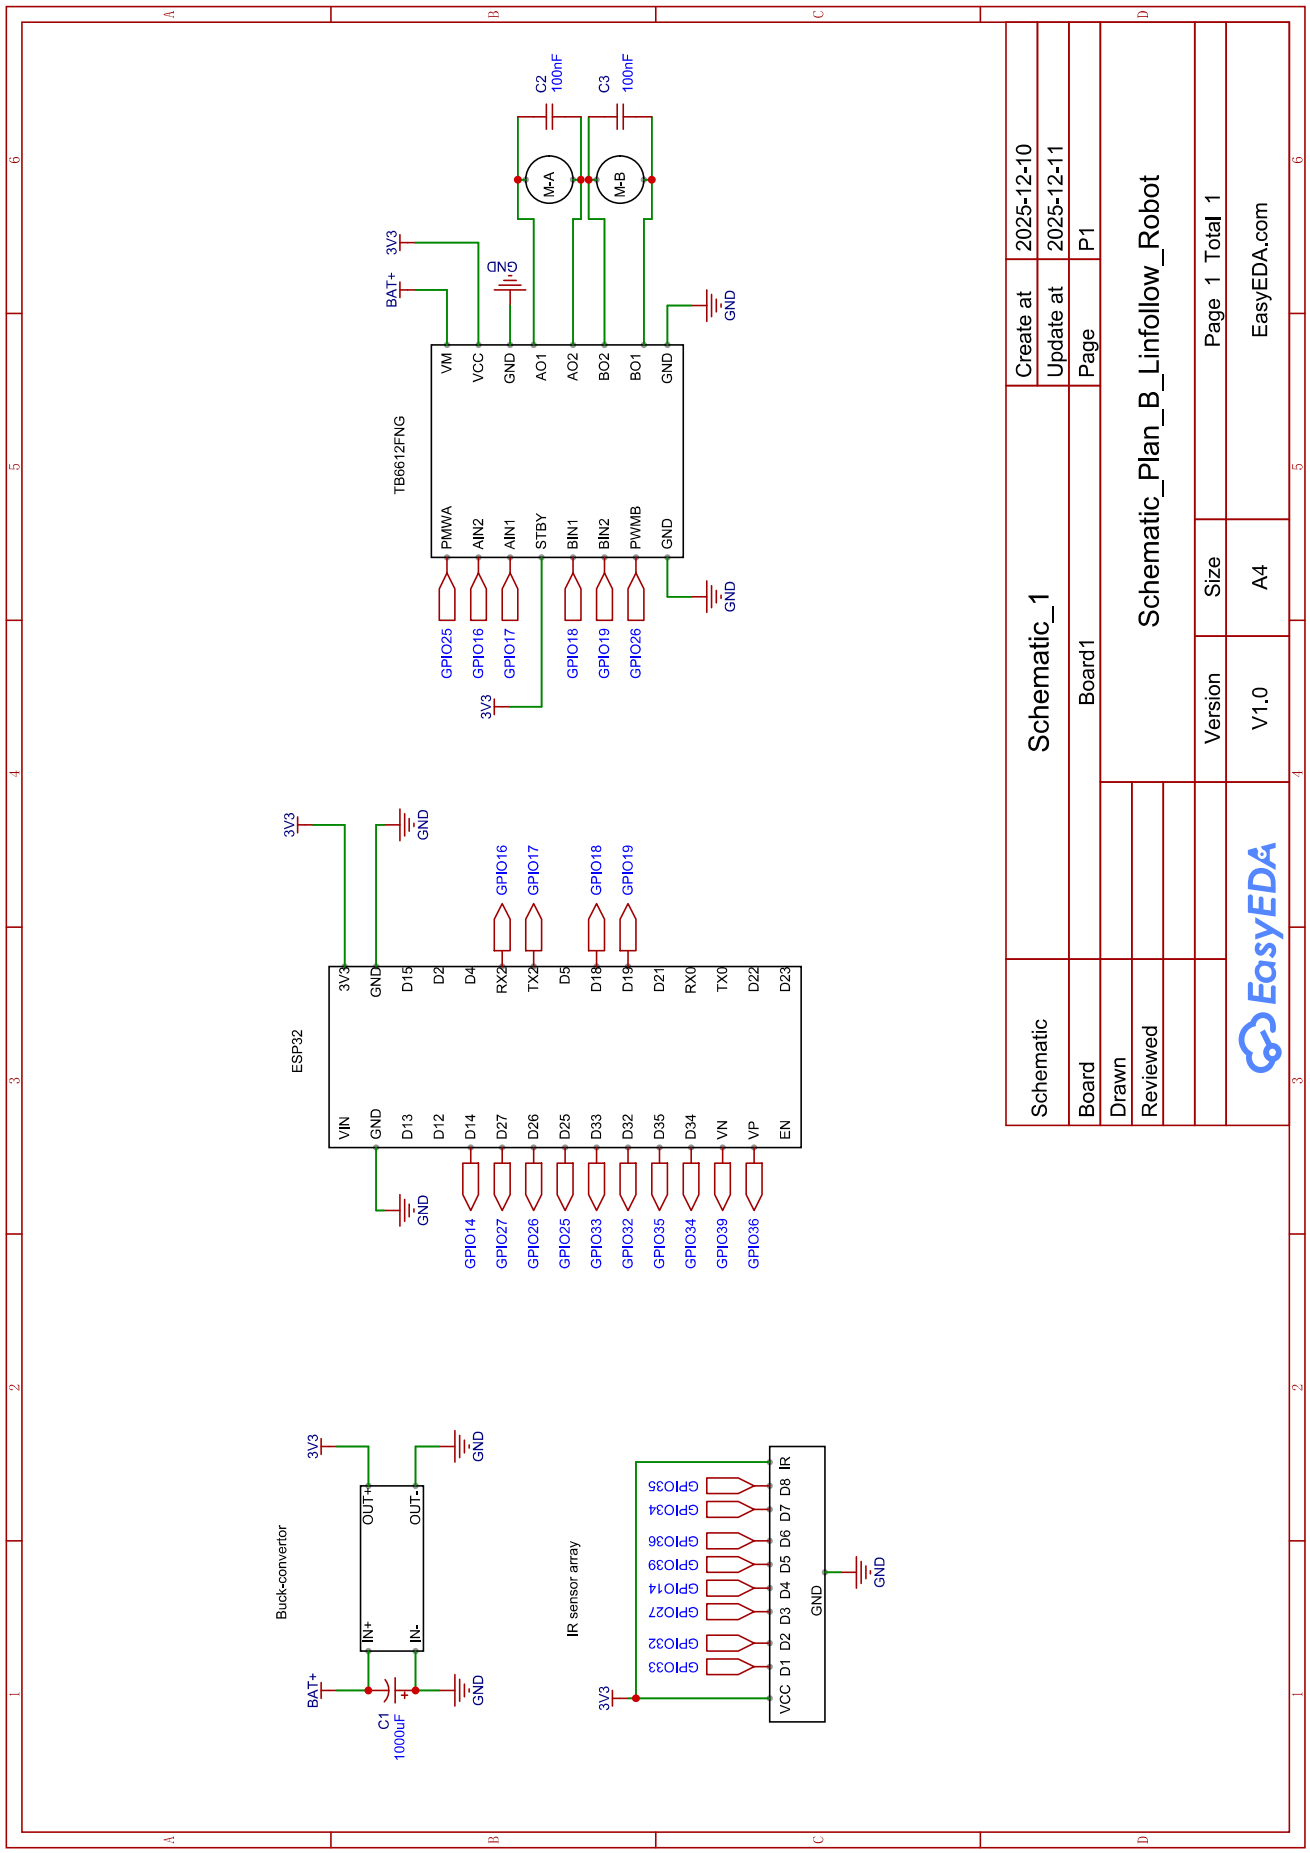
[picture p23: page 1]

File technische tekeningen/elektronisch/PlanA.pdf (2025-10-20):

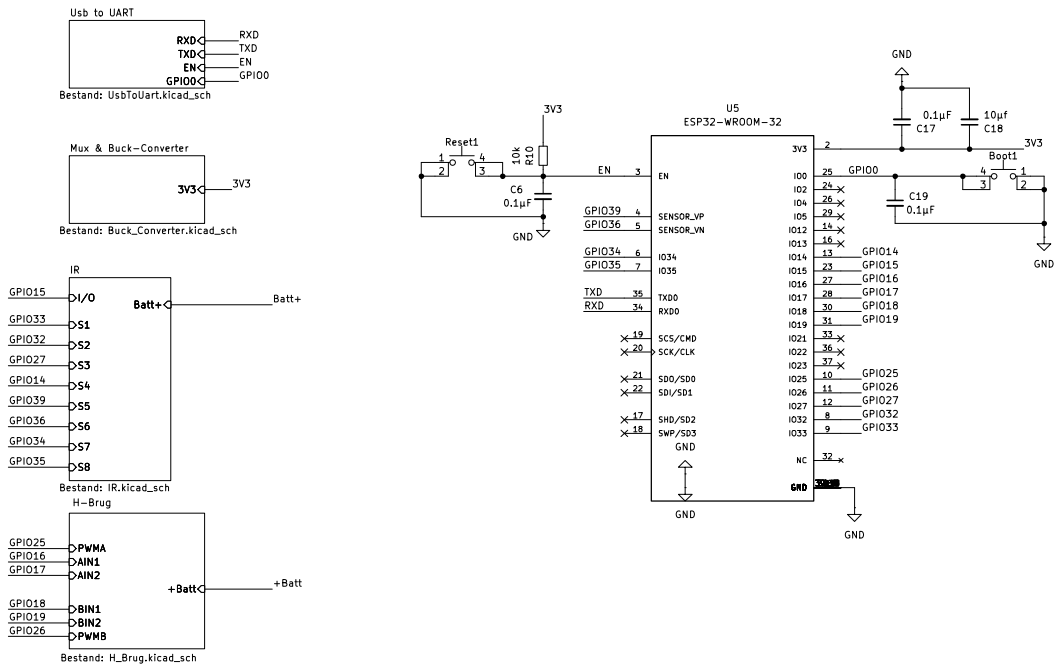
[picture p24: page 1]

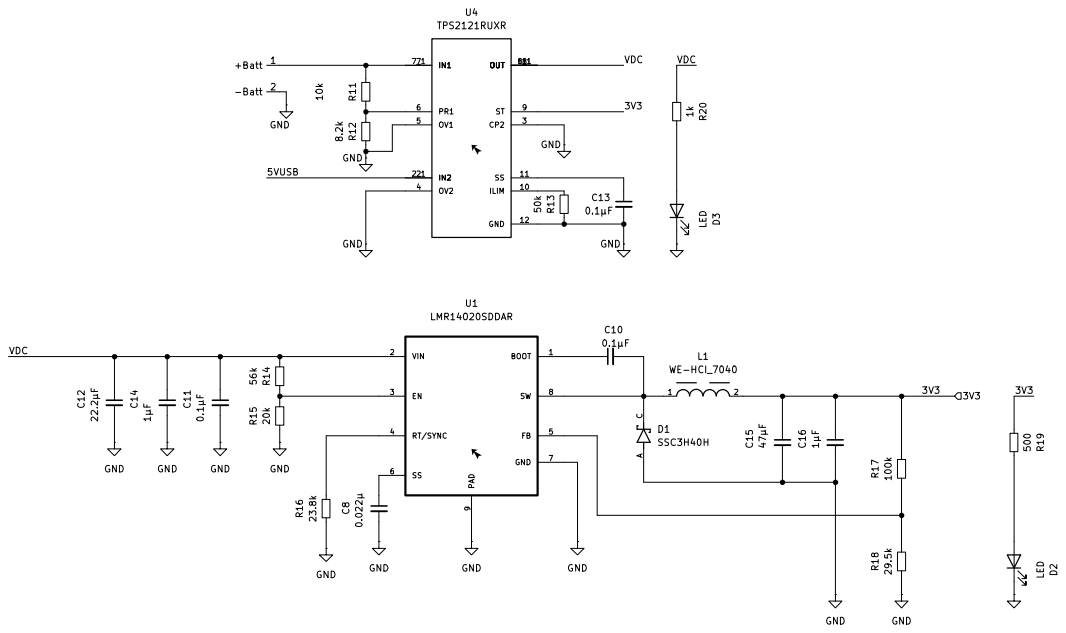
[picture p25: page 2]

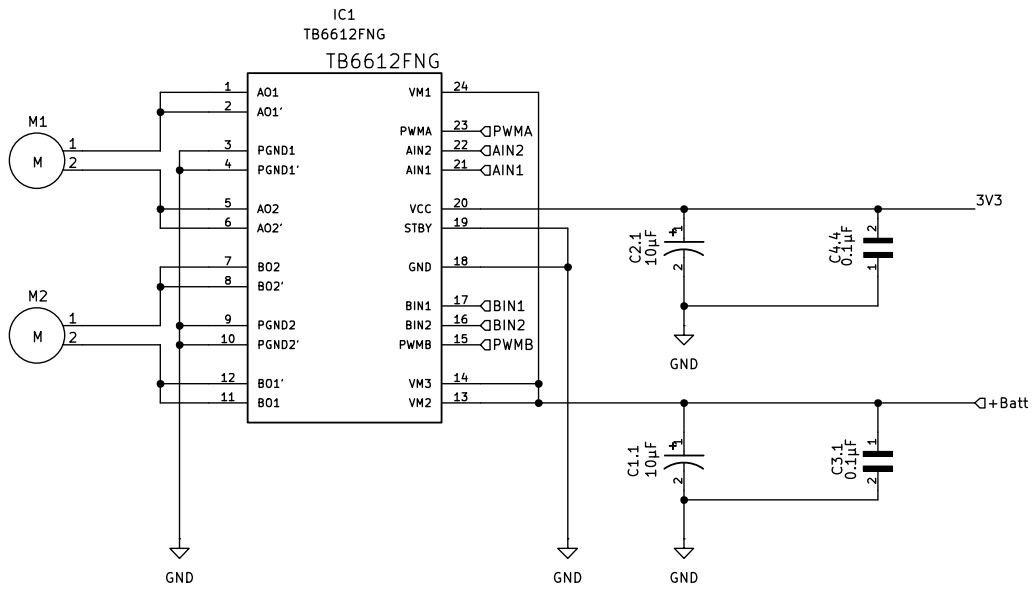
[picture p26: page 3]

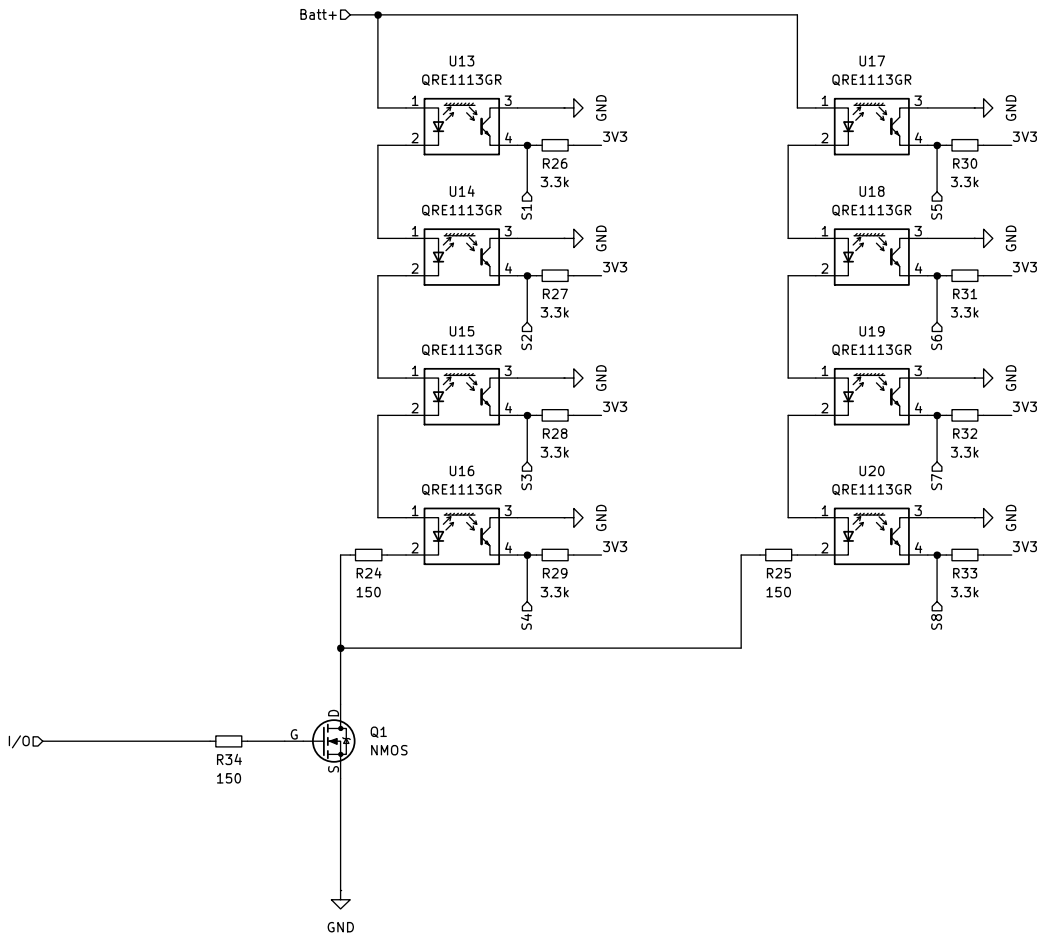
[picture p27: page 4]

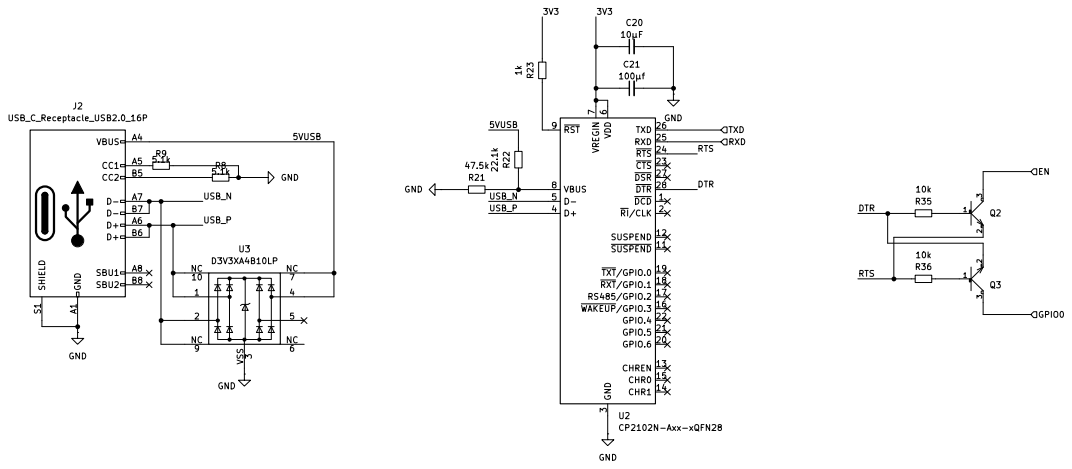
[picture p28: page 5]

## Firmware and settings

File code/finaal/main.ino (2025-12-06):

#include <BluetoothSerial.h>
#include <TB6612.h>
#include <EEPROM.h>

BluetoothSerial SerialBT;

#define EEPROM_SIZE 512 // aantal bytes
#define EEPROM_FIRST_CHECK 0xBEEDCAFE // voor eerste flash van ESP
#define CHECK_ADDR 500 // Oude Check Adres, niet meer nodig maar voor backward compatibility


// DEBUG Toggle
#define DEBUG 0  // 0 = off , 1 = on 
#if DEBUG 
  #define Debug_println(x) Serial.println(x)
  #define Debug_print(x) Serial.print(x)
#else 
  #define Debug_print(x)
  #define Debug_println(x)
#endif

// --- STRUCTUREN ---

struct Motor {
  uint8_t nummer;
  int speed; // snelheid van motor 
  const uint8_t pwm;
  const uint8_t in1; // in 1 pin
  const uint8_t in2; // in 2 pin
};

struct Sensor {
  const char* naam;
  const uint8_t pin; 
  uint16_t zwart; // uit eeprom
  uint16_t wit; // uit eeprom
  int waarde; //raw
  int norm;  // genormaliseerd
};

struct pidController {
  float kp, ki, kd;
  float error;
  float lastError;
  float integral;
  float derivative;
  float output;
};

struct timer{
  uint32_t time;
  const uint16_t interval;
};

struct varIntervalTimer{
  uint32_t time;
  uint16_t interval;
};

struct status{
  bool run;
  bool verbonden;
  bool inSyncGestuurd;
  bool eenLijn;
};

struct ConfigParams {
  float kp, ki, kd;
  uint16_t power;
  uint16_t interval; // calc.interval
  float filterAlpha;
  uint16_t contrastDrempel;
};


Sensor sensoren[] = {
  {"DP_1", 33, 4095, 0, 0},
  {"DP_2", 32, 4095, 0, 0},
  {"DP_3", 27, 4095, 0, 0},
  {"DP_4", 14, 4095, 0, 0},
  {"DP_5", 39, 4095, 0, 0},
  {"DP_6", 36, 4095, 0, 0},
  {"DP_7", 34, 4095, 0, 0},
  {"DP_8", 35, 4095, 0, 0},
};

Motor motoren[]{
  {1, 0, 25, 17, 16},
  {2, 0, 26, 18, 19},
};

status robot;

pidController pid; // Operationeel PID struct
ConfigParams params; // EEPROM opslag struct

varIntervalTimer calc{0,2000};
varIntervalTimer send{0,200}; // interval voor telementry data 

timer ping{0,20000}; // vaste interval timer in millis onderhoud bt connectie
timer eepromCommitTimer{0, 2000}; //  Debounce timer voor EEPROM commit

const uint8_t AANTAL_SENSOREN = sizeof(sensoren) / sizeof(sensoren[0]);
const uint8_t AANTAL_MOTOREN = sizeof(motoren) / sizeof(motoren[0]);

uint16_t power = 0; // Gebruikt nu params.power, maar behouden voor backward compatibility in updatePID.
float filterAlpha = 0.8f; // Gebruikt nu params.filterAlpha
uint16_t contrastDrempel = 250; //  Gebruikt nu params.contrastDrempel

float position = 0;
float filterPosition = 0;

static unsigned long lastTime = 0; // Voor PID Delta t
bool telementry = true; // normaal telementry aan als GUI opstart
bool vorigeLijnStatus = true;
bool configChanged = false; //"Dirty" flag voor EEPROM

MotorDriver motors(
  motoren[0].pwm, motoren[0].in1, motoren[0].in2, 
  motoren[1].pwm, motoren[1].in1, motoren[1].in2
);

// Dynamische EEPROM Adressen 
struct eepromOffsets{
  const uint16_t checkAddr = 0;
  const uint16_t paramsAddr = sizeof(EEPROM_FIRST_CHECK); // Start direct na de 4-byte check
  const uint16_t witAddr = paramsAddr + sizeof(ConfigParams);
  const uint16_t zwartAddr = witAddr + (AANTAL_SENSOREN * sizeof(uint16_t));
};

eepromOffsets adressen; // Adressen struct

void setup() {
  Serial.begin(115200);
  SerialBT.begin("LineFollow_V2"); // init bt
  EEPROM.begin(EEPROM_SIZE);
  motors.motor_init();   // init motordriver

  // first flash veilige waarden zetten 
  uint32_t first;
  EEPROM.get(adressen.checkAddr, first); // Gebruik nieuwe checkAddr
  
  if(first != EEPROM_FIRST_CHECK){
    Debug_println("Eerste flash of EEPROM gereset. Schrijf veilige defaults.");
    
    // Default sensorwaarden
    for (uint8_t i = 0; i < AANTAL_SENSOREN; i++) {
      // Gebruik nieuwe adressen
      EEPROM.put(adressen.witAddr + i * sizeof(uint16_t), sensoren[i].wit);
      EEPROM.put(adressen.zwartAddr + i * sizeof(uint16_t), sensoren[i].zwart);
    }

    // Default ConfigParams struct
    ConfigParams defaultParams = {
      1.0f, 0.0f, 0.0f, // kp, ki, kd
      50, // power
      2000, // calc.interval
      0.8f, // filterAlpha
      250 // contrastDrempel
    };
    EEPROM.put(adressen.paramsAddr, defaultParams); // Schrijf het hele blok ConfigParams

    first = EEPROM_FIRST_CHECK;
    EEPROM.put(adressen.checkAddr, first);
    EEPROM.commit();
  }
  
  //Lees EEPROM waarden in struct

  //PID & Config
  EEPROM.get(adressen.paramsAddr, params);
  
  pid.kp = params.kp; 
  pid.ki = params.ki; 
  pid.kd = params.kd;
  power = params.power;
  calc.interval = params.interval;
  filterAlpha = params.filterAlpha;
  contrastDrempel = params.contrastDrempel;

  //Sensor Normalisatie waarden
  for (uint8_t i = 0; i < AANTAL_SENSOREN; i++) {
    EEPROM.get(adressen.witAddr + i * sizeof(uint16_t), sensoren[i].wit);
    EEPROM.get(adressen.zwartAddr + i * sizeof(uint16_t), sensoren[i].zwart);
  }
}


void loop() {
  uint32_t nuMillis = millis();
  uint32_t nuMicros = micros();
  
  // BT Altijd actieve checks
  if (SerialBT.available()) {
    String msg = SerialBT.readStringUntil('\n');
    msg.trim();
    // Debug_println("Ontvangen: " + msg);

    // PING / PONG handshake
    if (msg == "PING") {
      SerialBT.println("PONG");
      robot.verbonden = true;
      ping.time = millis();
    }
    // Verwerk JSON berichten
    else if (msg.startsWith("{") && msg.endsWith("}")) {

      // Essentiële commando's (run, telem) ALTIJD  verwerken
      if (msg.indexOf("\"run\"") != -1)  {
        bool newRunStatus = msg.indexOf("\"true\"") != -1;
        robot.run = newRunStatus; // Update status

        // Als de nieuwe status STOP is (false), zet de motoren struct direct stil
        if (!robot.run) { 
          motoren[0].speed = 0; // Zet motoren stil in struct
          motoren[1].speed = 0; // Zet motoren stil in struct
        }
      }
      
      // Telementry aan/uit 
      else if (msg.indexOf("\"telem\"") != -1) {
        telementry = msg.indexOf("\"true\"") != -1;
      }
      
      // Configuratie en manuele commando's verwerken ALLEEN als de robot.run = false is
      else if (!robot.run) {
        if (msg.indexOf("\"motor\"") != -1) handleManMotorSpeed(parseMotorJson(msg));
        else if (msg.indexOf("\"pid\"") != -1) handlePid(msg);
        else if (msg.indexOf("\"interval\"") != -1) handleInterval(msg);
        else if (msg.indexOf("\"speed\"") != -1) handleSpeed(msg);
        else if (msg.indexOf("\"filter\"") != -1) handleFilter(msg);
        else if (msg.indexOf("\"contrast\"") != -1) handleContrast(msg);
        else if (msg.indexOf("\"calib\"") != -1) {
          if (msg.indexOf("\"white\"") != -1) calibWit();
          else if (msg.indexOf("\"black\"") != -1) calibZwart();
        }
      }
    }
  }

  // EEPROM DEBOUNCED COMMIT LOGICA 
  // Dit zorgt ervoor dat meerdere config wijzigingen in één keer worden weggeschreven na een pauze van 2s.
  if (configChanged && (nuMillis - eepromCommitTimer.time >= eepromCommitTimer.interval)) {
    ConfigParams oldParams;
    EEPROM.get(adressen.paramsAddr, oldParams);
    
    // Gebruik memcmp om te controleren of er bytes zijn veranderd
    if (memcmp(&oldParams, &params, sizeof(ConfigParams)) != 0) {
      EEPROM.put(adressen.paramsAddr, params); // Schrijf het hele blok
      EEPROM.commit(); 
      Debug_println("EEPROM Config parameters committed na debouncing.");
    }
    
    configChanged = false; // Reset de flag
  }

  // TIMEOUT CONTROLE
  if (robot.verbonden && (nuMillis - ping.time > ping.interval)) {
    robot.verbonden = false;
    robot.inSyncGestuurd = false;
    Debug_println("Verbinding verbroken");
  }

  // TELEMENTRY VERZENDEN
  if(robot.verbonden && telementry){
    if (nuMillis - send.time >= send.interval) {
      send.time = nuMillis;
      // Stuur sensorwaarden, position, output
      for (uint8_t i = 0; i < AANTAL_SENSOREN; i++) {
        Sensor& s = sensoren[i];
        String json = JsonFormat(s.naam, s.norm);
        SerialBT.println(json);
      }
      String json = JsonFloatFormat("position", filterPosition);
      SerialBT.println(json);
      json = JsonFloatFormat("output", pid.output);
      SerialBT.println(json);
      
      // Stuurt eenmalig een sync bericht met de app (voor PID & power)
      if(robot.inSyncGestuurd == false && SerialBT.hasClient()){
        String json = JsonFormat("speed", power);
        SerialBT.println(json);
            
        json = JsonFormat("interval", calc.interval);
        SerialBT.println(json);
        
        json = JsonFloatFormat("filter", filterAlpha);
        SerialBT.println(json);
        
        json = JsonFormat("contrast", contrastDrempel);
        SerialBT.println(json);
            
        char c[512]; 
        sprintf(c, "{\"pid\": {\"kp\": %.2f, \"ki\": %.2f, \"kd\": %.2f}}", pid.kp, pid.ki, pid.kd);
        json = String(c);
        SerialBT.println(json);
            
        robot.inSyncGestuurd = true; // zet in sync flag hoog 
      }
    }
  }

  // --- REGELSYCLUS (DO CYCLUS) ---
  if (nuMicros - calc.time >= calc.interval){
    calc.time = nuMicros;
    unsigned long start = micros();
    
    // normaliseer sensor waarden 
    sensorNormalisatie();

    // Bepaal de zwaarste sensor
    uint8_t index = 0;
    for (uint8_t i = 1 ; i < AANTAL_SENSOREN; i++){
      if(sensoren[i].norm > sensoren[index].norm) index = i;
    }

    // controle op lijn 
    bool huidigeLijnStatus = geenLine(contrastDrempel);
    
    // Op positieve edge (van 'lijn gevonden' naar 'geen lijn') de motoren en run stil leggen
    if  (huidigeLijnStatus == true && vorigeLijnStatus == false){ 
      robot.run = false;
      motoren[0].speed = 0; // Zet motoren stil in struct
      motoren[1].speed = 0; // Zet motoren stil in struct
      
      // Verzend feedback naar GUI
      if (robot.verbonden) {
        SerialBT.println("{\"status\": \"LOST_LINE\"}"); 
      }
    }

    vorigeLijnStatus =  huidigeLijnStatus;

    // Kwadratische interpolatie voor positiebepaling
    float s1 = sensoren[index].norm;
    float s0;
    if (index == 0) {
        s0 = 0.0f; // Virtuele sensor 0
    } else {
        s0 = sensoren[index - 1].norm;
    }

    float s2;
    if (index == AANTAL_SENSOREN - 1) {
        s2 = 0.0f; // Virtuele sensor 0
    } else {
        s2 = sensoren[index + 1].norm;
    }

    float offset = 0.0f;
    float denom = (s2 + s0) - 2.0f * s1;
    if (fabs(denom) > 0.001f) {
        offset = 0.5f * (s2 - s0) / denom;
    }

    float mid = (float)index + offset;
    float center = (AANTAL_SENSOREN - 1) / 2.0f;
    float scale = 60.0f / (AANTAL_SENSOREN - 1);
    position = (mid - center) * scale;
    
    // Laag doorlaatfilter (Gebruikt nu filterAlpha)
    filterPosition = (1.0f - filterAlpha) * filterPosition + filterAlpha * position;

    // PID-controle
    if (robot.run) {
      updatePID(filterPosition, power);
    } 

    // Aansturen van motoren (Single Point of Control)
    motors.set_speed(motoren[0].speed, motoren[1].speed);

    unsigned long end = micros();
  }
}


// return true als geen lijn , false als wel lijn 
bool geenLine(int contrastDrempel) { 
  int minWaarde = sensoren[0].norm;
  int maxWaarde = sensoren[0].norm;
    
  for (uint8_t i = 1; i < AANTAL_SENSOREN; i++) { 
    if(sensoren[i].norm > maxWaarde) maxWaarde = sensoren[i].norm;
    if(sensoren[i].norm < minWaarde) minWaarde = sensoren[i].norm; 
  }

  int contrast = maxWaarde - minWaarde;
  if (contrast < contrastDrempel) {
      return true; // Contrast te klein = GEEN LIJN 
  } 
  else { 
      return false;
  } 
}

String JsonFormat(const char* naam, int waarde){
  char c[100];
  sprintf(c, "{\"%s\": %d}", naam , waarde);
  return String(c);
}

String JsonFloatFormat(const char* naam, float waarde) {
  char c[100];
  sprintf(c, "{\"%s\": %.2f}" , naam , waarde);
  return String(c);
}

// markeert de configuratie als 'dirty' om EEPROM commit te triggeren
// dirty betekent dat de waarde in RAM niet gelijk is aan de waarde in EEPROM
// we markeren dat er een configchange moet gebeuren maar in de loop wachten we
// pushen we de verandering maar om de 2s om EN niet als robot.run true is 
void markConfigAsDirty() {
  configChanged = true;
  eepromCommitTimer.time = millis(); // Reset de timer
}

// sensor calibratie witte waarden 
void calibWit() {
  for (uint8_t i = 0; i < AANTAL_SENSOREN; i++) {
    uint16_t value = analogRead(sensoren[i].pin);
    sensoren[i].wit = value;
    int address = adressen.witAddr + i * sizeof(uint16_t);
    EEPROM.put(address, value);
  }
  EEPROM.commit();
  Debug_println("Witte kalibratie opgeslagen");
}

// sensor calibratie zwarte waarden 
void calibZwart() {
  for (uint8_t i = 0; i < AANTAL_SENSOREN; i++) {
    uint16_t value = analogRead(sensoren[i].pin);
    sensoren[i].zwart = value;
    int address = adressen.zwartAddr + i * sizeof(uint16_t);
    EEPROM.put(address, value);
  }
  EEPROM.commit();
  Debug_println("Zwarte kalibratie opgeslagen");
}

void sensorNormalisatie() {
  for (uint8_t i = 0; i < AANTAL_SENSOREN; i++) {
    Sensor& s = sensoren[i];
    int reading = analogRead(s.pin);
    s.waarde = reading;
    s.norm = map(s.waarde,s.wit,s.zwart,0,4095);
  }
}

void updatePID(float position, int baseSpeed) {
  unsigned long now = millis();
  float dt = (float)(now - lastTime) / 1000.0f;
  lastTime = now;
  
  pid.error = -position;
  
  // I-term 
  pid.integral += pid.error * dt;
  pid.integral = constrain(pid.integral, -1000, 1000);

  // D-term
  if (dt > 0.0001f) { 
    pid.derivative = (pid.error - pid.lastError) / dt;
  } else {
    pid.derivative = 0.0f;
  }
  pid.lastError = pid.error;
  
  // PID berekening
  pid.output = pid.kp * pid.error
             + pid.ki * pid.integral
             + pid.kd * pid.derivative;
  pid.output = constrain(pid.output, -510, 510);

  int powerRight = constrain(baseSpeed - pid.output, -255, 255);
  int powerLeft  = constrain(baseSpeed + pid.output, -255, 255);

  motoren[0].speed = powerLeft;
  motoren[1].speed = -powerRight;
}

// CONFIG HANDLERS 
void handlePid(const String& msg) {
  params.kp = haalJsonWaarde(msg, "kp").toFloat();
  params.ki = haalJsonWaarde(msg, "ki").toFloat();
  params.kd = haalJsonWaarde(msg, "kd").toFloat();

  // Update operationele PID struct direct in RAM
  pid.kp = params.kp; pid.ki = params.ki; pid.kd = params.kd;

  markConfigAsDirty();
}

void handleInterval(const String& msg) {
  params.interval = haalJsonWaarde(msg, "interval").toInt();
  // Update operationele variabele
  calc.interval = params.interval; 
  
  markConfigAsDirty();
}

void handleSpeed(const String& msg) {
  params.power = constrain(haalJsonWaarde(msg, "speed").toInt(), 0, 255);
  // Update operationele variabele
  power = params.power; 
  
  markConfigAsDirty();
}

void handleFilter(const String& msg) {
  params.filterAlpha = constrain(haalJsonWaarde(msg, "filter").toFloat(), 0.0f, 1.0f);
  // Update operationele variabele
  filterAlpha = params.filterAlpha; 
  
  markConfigAsDirty();
}

void handleContrast(const String& msg) {
  params.contrastDrempel = constrain(haalJsonWaarde(msg, "contrast").toInt(), 0, 4095);
  // Update operationele variabele
  contrastDrempel = params.contrastDrempel; 
  
  markConfigAsDirty();
}

// JSON PARSERS
String haalJsonWaarde(const String& msg, const String& key) {
  int keyIndex = msg.indexOf("\"" + key + "\"");
  if (keyIndex == -1) return "";

  int colonIndex = msg.indexOf(":", keyIndex);
  if (colonIndex == -1) return "";
  int commaIndex = msg.indexOf(",", colonIndex);
  if (commaIndex == -1) commaIndex = msg.indexOf("}", colonIndex);

  if (commaIndex == -1) return "";
  String value = msg.substring(colonIndex + 1, commaIndex);
  value.trim();
  value.replace("\"", "");
  return value;
}

// Manueel bedienen van motor terwijl motor run false is kan 
Motor parseMotorJson(const String& msg) {
  Motor m = {0, 0, 0, 0, 0};
  m.nummer = haalJsonWaarde(msg, "motor").toInt();
  m.speed  = haalJsonWaarde(msg, "value").toInt();
  return m;
}

void handleManMotorSpeed(const Motor& m){
  if (m.nummer < 1 || m.nummer > 2) return; // motor.nummer 1 of 2
  motoren[m.nummer - 1].speed = m.speed; // m.nummer 1 is array index 0 , 2 is 1 
  
  Debug_print("Motor: "); Debug_print(m.nummer);
  Debug_print(" Value: ");Debug_println(m.speed);
}

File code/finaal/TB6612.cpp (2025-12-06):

#include <TB6612.h>
#include <Arduino.h>
#include "soc/gpio_struct.h" // helper voor GPIO
#include "soc/gpio_reg.h"

// Constructor
MotorDriver::MotorDriver(uint8_t pwmA, uint8_t in1A, uint8_t in2A, uint8_t pwmB, uint8_t in1B, uint8_t in2B)
{
  pwmA_pin = pwmA;
  in1A_pin = in1A;
  in2A_pin = in2A;
  pwmB_pin = pwmB;
  in1B_pin = in1B;
  in2B_pin = in2B;
  

  pwm_freq = 5000;  // standaard 5 kHz
  pwm_res = 8;      // standaard 8-bit
}

void MotorDriver::motor_init(void)
{
  // pin setup
  pinMode(in1A_pin, OUTPUT);
  pinMode(in2A_pin, OUTPUT);
  pinMode(in1B_pin, OUTPUT);
  pinMode(in2B_pin, OUTPUT);
  pinMode(pwmA_pin, OUTPUT);
  pinMode(pwmB_pin, OUTPUT);

  // configureer LEDC PWM
  if (!ledcAttach(pwmA_pin, pwm_freq, pwm_res)) {
    Serial.println("PWM A attach failed!");
  }
  
  if (!ledcAttach(pwmB_pin, pwm_freq, pwm_res)) {
    Serial.println("PWM B attach failed!");
  }

  // reset alle GPIO schakelregisters 
  GPIO.out_w1tc = (1 << in1A_pin) | (1 << in2A_pin) | (1 << in1B_pin) | (1 << in2B_pin);
}

void MotorDriver::set_speed(int16_t motor_a, int16_t motor_b)
{
  int16_t maxDuty = (1 << pwm_res) - 1;

  motor_a = constrain(motor_a, -maxDuty, maxDuty);
  motor_b = constrain(motor_b, -maxDuty, maxDuty);

  // duty berekenen
 
  uint32_t dutyA = abs(motor_a);
  uint32_t dutyB = abs(motor_b);



  // motor A richting
  if (motor_a > 0) {
    GPIO.out_w1ts = (1 << in1A_pin); // 1A hoog 
    GPIO.out_w1tc = (1 << in2A_pin); // 2A laag 
  } else if (motor_a < 0) {
    GPIO.out_w1tc = (1 << in1A_pin); // 1A laag
    GPIO.out_w1ts = (1 << in2A_pin); // 2A hoog
  }

  // motor B richting
  if (motor_b > 0) {
    GPIO.out_w1ts = (1 << in1B_pin); // 1B hoog
    GPIO.out_w1tc = (1 << in2B_pin); // 2B laag
  } else if (motor_b < 0) {
    GPIO.out_w1tc = (1 << in1B_pin); // 1B laag
    GPIO.out_w1ts = (1 << in2B_pin); // 2B hoog
  } 

  // PWM duty schrijven
  ledcWrite(pwmA_pin, dutyA);
  ledcWrite(pwmB_pin, dutyB);
}

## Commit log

2025-11-12 Basis H-brug,
    Voorbeeld set_speed(motorA, motorB)
    .cpp ,basis bibliotheek zet freq en resolutie
    .h
2025-11-12 Basis Sensor Reading
    print de waarde van elke sensor op de pinnen
2025-11-12 Enhance readme with detailed usage instructions
    Updated the readme with detailed instructions on battery usage, wireless communication, commands, calibration, and settings for the robot.
2025-12-06 Fix formatting and enhance PID parameters section
    Corrected formatting and added details about PID parameters in the readme.
2025-12-09 Optimize motor control using GPIO registers
    Updated motor control logic to use GPIO registers instead of digitalWrite for improved performance. Added GPIO configuration for motor direction control.
2025-12-09 Refactor MotorDriver constructor and pin definitions
    Refactor MotorDriver constructor and clean up comments.
2025-12-09 Enhance readme with motor direction logic details
    Added detailed explanation of motor direction logic.
2025-12-09 Fix formatting in readme for motor direction section
2025-12-09 Revise bill of materials with updated components
    Updated the bill of materials with detailed component information and total calculations.
2025-12-10 Rename project title and update description
    Updated the title and content of the BOM readme.
2025-12-10 Revise assembly instructions and update steps
    Updated instructions for assembling and wiring components, including changes to the steps for connecting sensors and finalizing the setup.
2025-12-13 De bestanden voor mijn plan A, (nooit getest)
    ik was begonnen met het ontwerpen van een PCB maar heb deze nooit afgewerkt
    hier zijn de bestanden voor het partiële ontwerp
